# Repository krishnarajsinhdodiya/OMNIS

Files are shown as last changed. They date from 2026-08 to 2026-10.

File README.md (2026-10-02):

# OMNIS

**O**mnidirectional **M**obility and **N**on-holonomic **I**nertial **S**tabilization

A four-wheel robot platform where every wheel is driven by its own stepper motor,
built from scratch on the ESP32-S3 as a personal embedded-systems portfolio
project.

Two headline capabilities:

1. **Holonomic drive** — mecanum angled-roller wheels give full directional
   control: strafe, rotate in place, and move diagonally without turning first.
2. **Self-balancing mode** — the platform can tip up and balance/drive on two
   wheels, Segway-style, in addition to normal four-wheel driving.

All four steppers stay powered during two-wheel balance mode. That is
deliberate: the platform must be able to balance on *either* side, so if it is
flipped mid-run the new pair of wheels is immediately drivable. The balance
controller detects which side is down and re-maps which two wheels provide
balance thrust.

---

## Where the working firmware is

> ### 👉 [`omnis-superloop-mvp/`](omnis-superloop-mvp/) — the complete, buildable firmware
>
> A **plain superloop with no FreeRTOS tasks, queues, semaphores or mutexes**.
> All seven stages are built, host-tested and committed: 500 Hz dual-IMU EKF,
> mecanum kinematics, CRSF radio, RMT step generation, fault handling, arming
> supervisor and the two-wheel balance controller.
>
> **Start at [`omnis-superloop-mvp/TESTING.md`](omnis-superloop-mvp/TESTING.md)
> §0 before applying power** — board Rev 2.0 hardwires the A4988 enable, so the
> motors are live whenever 12 V is present.

The repository holds **two** firmware trees, and it is worth being clear about
which is which:

| Tree | What it is | State |
|---|---|---|
| [`omnis-superloop-mvp/`](omnis-superloop-mvp/) | The **deadline build**. Bare superloop, no RTOS primitives, everything needed to drive and balance | **Complete**, host-tested, awaiting bench bring-up on the assembled Rev 2.0 board |
| `main/` (repository root) | The **future FreeRTOS build** described in [`assets/documentation/omnis-info.md`](assets/documentation/omnis-info.md) | Still at the ESP-IDF hello-world stage — a placeholder, not abandoned work |

The superloop MVP exists because the full RTOS architecture is a learning
project with a longer runway than the delivery deadline allowed. Features left
out of it — OLED and buttons, microSD/FATFS and `params.json`, data logging,
OTA/Wi-Fi, battery sensing — are **deferred, not abandoned**, and the design for
each is already written down in the info file.

---

## Repository layout

```
OMNIS/
├── omnis-superloop-mvp/            ★ the working firmware — start here
│   ├── main/                         44 sources; see OPERATIONS_GUIDE.md §3
│   │   ├── main.c                    boot sequence + the superloop itself
│   │   ├── tick.{c,h}                500 Hz GPTimer, one flag, no RTOS
│   │   ├── imu.{c,h} mpu6050.*       dual MPU6050 over I²C
│   │   ├── attitude_ekf.* imu_fusion.*   per-IMU EKF + inverse-covariance fusion
│   │   ├── mecanum_kinematics.*      IK/FK for the parallel-roller layout
│   │   ├── drive.{c,h}               sticks → body velocity → wheel rates
│   │   ├── crsf*.{c,h} rc_input.*    ExpressLRS radio
│   │   ├── step_wave.* step_gen.*    STEP pulses via the RMT peripheral
│   │   ├── balance.{c,h} pid.*       two-wheel balance controller
│   │   ├── fault.* buzzer*.* supervisor.*   safety and arming
│   │   └── omnis_{pins,params,config}.*     board map, tunables, switches
│   ├── test/                         7 host suites, no hardware needed
│   ├── OPERATIONS_GUIDE.md           build, architecture, file index, tuning
│   ├── TESTING.md                    bench bring-up, stage by stage
│   ├── README.md                     overview and stage status
│   └── BUILD-LOG.md                  scope, decisions, construction history
│
├── assets/
│   ├── kinematics/                   drivetrain maths, derived from scratch
│   │   ├── mecanum-kinematics-derivation.md     the full derivation
│   │   ├── mecanum-kinematics-reference.md      equations and verified numbers
│   │   ├── mecanum-kinematics-code-explained.md line-by-line walkthrough
│   │   └── mecanum_kinematics.{c,h}             the module itself
│   ├── control/                      EKF, fusion and PID: derivations + modules
│   ├── documentation/
│   │   ├── omnis-info.md             full design spec + what the MVP does — ONE copy
│   │   ├── s3-pro-docs/              board pinout, datasheet, CAD model
│   │   └── setup-guides/             toolchain, VS Code, ESP32 command reference
│   └── pcb/                          KiCad project and schematics
│
├── main/                             future FreeRTOS build (hello-world stub)
├── CMakeLists.txt                    root ESP-IDF project
├── .devcontainer/                    QEMU/Linux container (no board access)
└── .vscode/
```

The modules under `assets/kinematics/` and `assets/control/` are **byte-identical**
to the copies in `omnis-superloop-mvp/main/`. They live in `assets/` with their
derivations so the maths and the code that implements it stay next to each other.

---

## Drivetrain — read this before touching the kinematics

The wheels are **not** in the textbook X-drive arrangement. Mounting-shaft and
motor constraints put the **same roller tilt on both left wheels** and the
mirrored tilt on **both right wheels**:

```
        FL  /                 \  FR          left  pair  FL, RL  ->  δ = -1
        RL  /                 \  RR          right pair  FR, RR  ->  δ = +1
```

The standard mecanum mixing matrix does not describe this robot. The inverse and
forward kinematics were **re-derived from first principles** for this layout —
see [`assets/kinematics/mecanum-kinematics-derivation.md`](assets/kinematics/mecanum-kinematics-derivation.md).

Four consequences worth knowing up front:

- **Strafe splits along the sides**, not the diagonals. The `vx = vy` bench test
  idles the whole **left side**, not the FL/RR diagonal.
- **The two axles have different yaw levers** — `(L+W)/2` at the front and
  `(L−W)/2` at the rear, a **64.7:1** ratio on this frame. During a pure spin
  the rear wheels barely turn. That is correct, not a fault.
- **Still fully holonomic and no slower.** `det(MᵀM) = 4L²`, non-zero for any
  real chassis, and the peak wheel rate per unit of commanded motion is
  unchanged — same top speed, strafe speed and yaw rate as an X-drive.
- **Odometry is noisier.** The strafe and yaw columns meet at 44° instead of
  90°, amplifying per-wheel error by 1.44× on `vy` and 2.03× on `w`.

The layout is stated in exactly one place — the four `MECANUM_DELTA_*` constants
in `mecanum_kinematics.h` — and everything else is computed from them. If the
robot strafes the wrong way, negate all four together; never fix it with a `DIR`
invert flag. [`OPERATIONS_GUIDE.md §4.2`](omnis-superloop-mvp/OPERATIONS_GUIDE.md)
has the two-direction bench test that tells the two failures apart.

---

## Hardware

| Module | Part | Notes |
|---|---|---|
| MCU | **ESP32-S3-WROOM-1-N16R8** on an EdgeHax S3 Pro dev board | 16 MB flash / 8 MB Octal PSRAM |
| Wheel motors (×4) | Nidec **KV4239-T3B004** | 2-phase hybrid stepper, NEMA17-class (42 mm) |
| Stepper drivers (×4) | **A4988** | Fixed 1/16 microstepping → 3200 microsteps/rev |
| Wheels (×4) | Mecanum omnidirectional, 60 mm | **Lateral parallel roller layout** — see above |
| IMUs (×2) | **MPU6050** at `0x68` and `0x69` | Diagonally opposite corners, mounted **antiparallel**; fused by inverse covariance |
| Display | **SSD1306** 128×64 I²C OLED | Deferred in the MVP |
| RC link | **RadioMaster Pocket** TX + **ExpressLRS Nano** Rx | CRSF over UART, 420000 baud |
| Storage | Onboard microSD (SPI mode, FAT32) | Deferred in the MVP |
| Buzzer | 3-pin buzzer module | Fault and failsafe cues |
| Buttons | 6× tactile | **Active-HIGH**, needs pull-downs. Deferred in the MVP |
| Power | 3S LiPo → **L7805CV** 5 V logic rail | Battery divider present; sensing deferred in the MVP |

Schematic: [`assets/pcb/`](assets/pcb/) (KiCad project, Rev 2.0).

### GPIO map — board Rev 2.0

Traced wire-by-wire from the KiCad schematic, not read off a drawing. The
authoritative copy is
[`omnis-superloop-mvp/main/omnis_pins.h`](omnis-superloop-mvp/main/omnis_pins.h).

| GPIO | Function |
|---|---|
| 4, 5 | Front-Left STEP / DIR |
| 40, 38 | Front-Right STEP / DIR |
| 15, 46 | Rear-Left STEP / DIR (46 is a strapping pin) |
| 21, 42 | Rear-Right STEP / DIR |
| 8, 9 | I²C SDA / SCL — OLED and both MPU6050s |
| 7 | IMU interrupt |
| 17, 18 | UART to the ExpressLRS receiver — ESP **TX** / **RX** |
| 16 | Buzzer |

**Three gotchas worth knowing before you wire or flash anything:**

- **`COM_ENA` is gone on Rev 2.0.** The A4988 enable is hardwired, so the motors
  are energised whenever 12 V is present — before the firmware runs, and while
  it is halted in a fault. Nothing in software can de-energise them. The
  failsafe is therefore "stop STEP pulses, motors hold", and setting the four
  `Vref` current limits is a **prerequisite to first power-up**, not a
  calibration step.
- The schematic's `RX` / `TX` net names are from the *receiver's* perspective.
  GPIO17 is the ESP32's **TX** and GPIO18 is its **RX** — the reverse of the
  labels. The firmware auto-detects the RX pin anyway.
- GPIO46 is a strapping pin and GPIO38–42 sit on the default JTAG pins.
  Everything behaves normally as long as nothing holds them through a power
  cycle.

---

## Firmware architecture (superloop MVP)

```
            GPTimer ISR (500 Hz) ── sets a volatile flag, nothing else
                     │
   app_main ─ while(1) ─ tick_wait() ─────────────────────────────────────────┐
     │                                                                        │
     │  1. SENSE   imu_update()      2× MPU6050 on I²C → mount → bias → EKF → fuse
     │             crsf_poll()       UART1 RX-only → CRSF parser → channels
     │                                                                        │
     │  2. JUDGE   faults            IMU comm/disagree · link loss · tilt · overrun
     │             supervisor        DISARMED / ARMED-FLAT / BAL-SETTLE / BALANCE
     │                                                                        │
     │  3. ACT     flat:     sticks → IK → clamp → deadband → slew ─┐         │
     │             balance:  lean PID (balance frame) → wheel pair ─┼→ step_gen_update()
     │             else:     step_gen_stop()                         │    RMT ISR chains
     │                                                               │    ~2 ms bursts
     │  4. REPORT  buzzer (every tick) · telemetry (once a second)            │
     └────────────────────────────────────────────────────────────────────────┘
```

**The no-RTOS rule.** No FreeRTOS primitive appears in OMNIS-authored code —
ESP-IDF driver internals are treated as hardware. It was checked mechanically,
not merely followed: neither the `main/` sources nor the undefined symbols of the
compiled `libmain.a` contain any FreeRTOS task, queue, semaphore, event-group,
timer or port symbol.

The superloop is pinned to **CPU1** with that core's idle-task watchdog disabled
— a superloop never yields, so the idle task never runs.

Full explanation, file index and tuning cheat sheet:
[`omnis-superloop-mvp/OPERATIONS_GUIDE.md`](omnis-superloop-mvp/OPERATIONS_GUIDE.md).

### Control and estimation

Each MPU6050 runs its own 4-state EKF — `[roll, pitch, gyro_bias_roll,
gyro_bias_pitch]` — with adaptive measurement noise that distrusts the
accelerometer whenever `|‖a‖ − 1g|` exceeds ~0.2 g, i.e. exactly when the
platform is accelerating rather than merely tilted. Because roll couples only to
`bias_roll` and pitch only to `bias_pitch`, the 4×4 filter decomposes **exactly**
into two independent 2-state filters — no matrix inverse anywhere.

A fusion layer takes the inverse-covariance-weighted average of the two
estimates and raises a fault if they disagree by more than 15°, failing safe
instead of averaging through a bad sensor. Disagreement is measured on the
**gravity vectors**, not on Euler angles, so it stays meaningful at any attitude.

Balance runs in a dedicated **balance frame** rather than the flat body frame,
because flat-frame pitch folds at exactly the balance point — 85° and 95° both
read 85°, losing the lean direction where a balancer most needs it. The
controller is an inner 500 Hz PID on lean angle (rate taken straight from the
gyro for latency) plus a slow 20 Hz outer loop that biases the lean setpoint to
bleed off sustained forward effort. There are no wheel encoders, so this is the
honest ceiling of the current BOM — an encoder pair is the single
highest-leverage hardware upgrade available.

### Safety

- **Arming supervisor** with LOW→HIGH edge consumption: a fault that clears
  while the switch is still up does not re-arm the robot on its own.
- **CRSF link-loss, IMU comm failure, IMU disagreement, tilt and loop overrun**
  all latch faults and stop STEP pulses within the same tick.
- **Failsafe policy:** "hold last value" is explicitly the wrong default here — a
  dropped link mid-deflection would leave the robot executing that command
  unattended.
- Balance mode refuses to arm with zero gains, because a zero-gain balancer
  simply falls over.

---

## Building

Requires **ESP-IDF v6.0.2** natively for hardware work. Activate it with the
tools script — `export.sh` looks for a Python 3.11 virtualenv while this install
runs on 3.14:

```bash
. ~/.espressif/tools/activate_idf_v6.0.2.sh
```

Build and flash the working firmware:

```bash
cd /Volumes/Projects/OMNIS && idf.py -C omnis-superloop-mvp build
```

```bash
cd /Volumes/Projects/OMNIS && idf.py -C omnis-superloop-mvp -p /dev/cu.usbmodem101 flash monitor
```

Run the host test suites — no hardware, no ESP-IDF:

```bash
cd /Volumes/Projects/OMNIS/omnis-superloop-mvp && ./test/run_host_tests.sh
```

Full setup, including the native-vs-devcontainer split, is in
[`assets/documentation/setup-guides/phase0-toolchain-environment.md`](assets/documentation/setup-guides/phase0-toolchain-environment.md).
The devcontainer has **no USB passthrough** — it is for QEMU experiments only.
All real board work happens natively.

---

## Status

| Stage (superloop MVP) | Built + host-tested | Verified on hardware |
|---|---|---|
| 1 Timing spine | ✅ | ✅ 2026-09-07 (Rev 1 board): 500 Hz, zero overruns |
| 2 Kinematics | ✅ | ✅ boot self-check passed on the FPU |
| 3 IMUs + EKF | ✅ | ✅ |
| 4 Radio | ✅ | ✅ |
| 5 Step generation | ✅ | ✅ |
| 6 Faults + supervisor | ✅ | ✅ |

Not known until the assembled Rev 2.0 board runs: real I²C time per tick, IMU
mounting descriptors, motor `DIR` polarities, radio channel order, and every
balance gain. All five are **parameters**, not code changes —
[`OPERATIONS_GUIDE.md §4`](omnis-superloop-mvp/OPERATIONS_GUIDE.md) is the cheat
sheet.

### Roadmap beyond the MVP

Everything deferred from the superloop build, in the order it is worth adding:

1. **FATFS mount + `params.json` loader** with its fallback chain — so tuning
   stops requiring a rebuild
2. **Data logging** to append-only JSON Lines under `/sdcard/logs/`
3. **On-board wheel encoders** — the single highest-leverage hardware upgrade,
   and what the velocity-bias outer loop is really waiting for
4. **OLED and the button/menu state machine**
5. **OTA over Wi-Fi** with a factory slot and rollback verified against a
   deliberately broken image
6. **The full FreeRTOS architecture** at the repository root, once it has been
   learned properly rather than adopted in a hurry

### Open questions

- Internal vs. external button pull-downs
- Heading-hold: hold-to-engage or press-to-toggle
- What the transmitter's trim potentiometer trims — static balance-setpoint bias
  or live control gain
- A4988 `Vref` current limits, unset until the motors are on the bench

---

## License

Not yet specified.

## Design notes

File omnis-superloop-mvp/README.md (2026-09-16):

# OMNIS Superloop MVP

Firmware for the OMNIS robot — four-wheel mecanum drive that can also stand up
and balance on either wheel pair — written as a **plain superloop with no FreeRTOS
tasks, queues, semaphores or mutexes**. It is the deadline build that gets the
robot driving and balancing before the full FreeRTOS architecture in
[`../assets/documentation/omnis-info.md`](../assets/documentation/omnis-info.md) is
learned and implemented. Deferred features are deferred, not abandoned.

**Target:** ESP32-S3 (EdgeHax S3 Pro / DevKitC-1 class), board Rev 2.0 · ESP-IDF v6.0.2

| Document | Read it for |
|---|---|
| **[TESTING.md](TESTING.md)** | Bench bring-up, stage by stage. **Start here before powering anything.** |
| **[OPERATIONS_GUIDE.md](OPERATIONS_GUIDE.md)** | Build and flash, the superloop explained, a file-by-file index, and the tuning cheat sheet |
| [BUILD-LOG.md](BUILD-LOG.md) | The full history: what was built, what was learned, every decision, every bug found. **Also holds the scope, the settled decisions 1a/1b/1c and the stage-by-stage commit table** — `PLAN.md` was folded into it once the build finished |
| [../assets/documentation/omnis-info.md](../assets/documentation/omnis-info.md) | **The project info file — one copy, for the whole project.** The full specification, with `> **Superloop MVP:**` notes under each section saying what this build actually does |

---

## What it does

| In scope | Where |
|---|---|
| 500 Hz loop: dual-MPU6050 attitude EKF, inverse-covariance fusion, 15° disagreement fault | `imu.c`, `attitude_ekf.c`, `imu_fusion.c` |
| 4-wheel mecanum IK/FK, re-derived for the **lateral parallel roller** layout | `mecanum_kinematics.c`, `drive.c` |
| CRSF / ExpressLRS radio: throttle→vx, yaw→w, pitch+roll→vx/vy, arm, mode, speed | `crsf*.c`, `rc_input.c` |
| STEP pulses for four A4988s on the RMT peripheral, nothing in the hot path | `step_wave.c`, `step_gen.c` |
| Buzzer fault / failsafe signalling, arming supervisor | `fault.c`, `buzzer*.c`, `supervisor.c` |
| Two-wheel balance: lean PID in a dedicated balance frame | `balance.c`, `pid.c` |

**Excluded — deferred, not abandoned:** OLED and buttons, microSD / FATFS and
`params.json`, data logging, OTA and Wi-Fi, battery voltage sensing.

---

## Architecture

```
            GPTimer ISR (500 Hz) ── sets a volatile flag, nothing else
                     │
   app_main ─ while(1) ─ tick_wait() ─────────────────────────────────────────┐
     │                                                                        │
     │  1. SENSE   imu_update()      2x MPU6050 on I2C → mount → bias → EKF → fuse
     │             crsf_poll()       UART1 RX-only → CRSF parser → channels
     │                                                                        │
     │  2. JUDGE   faults            IMU comm/disagree · link loss · tilt · overrun
     │             supervisor        DISARMED / ARMED-FLAT / BAL-SETTLE / BALANCE
     │                                                                        │
     │  3. ACT     flat:     sticks → IK → clamp → deadband → slew ─┐         │
     │             balance:  lean PID (balance frame) → wheel pair ─┼→ step_gen_update()
     │             else:     step_gen_stop()                         │    RMT ISR chains
     │                                                               │    ~2 ms bursts
     │  4. REPORT  buzzer (every tick) · telemetry (once a second)            │
     └────────────────────────────────────────────────────────────────────────┘
```

**The no-RTOS rule** (BUILD-LOG.md, Planning 1a): no RTOS primitive in OMNIS-authored code.
ESP-IDF driver internals are treated as hardware. The rule was checked mechanically,
not just followed: neither `main/` source nor the undefined symbols of the compiled
`libmain.a` contain any FreeRTOS task, queue, semaphore, event-group, timer or port
symbol.

**On board Rev 2.0 the A4988 enable is hardwired**, so the motors are energised
whenever 12 V is present and the supervisor is the entire safety story: STEP pulses
exist only while armed. Read TESTING.md §0.

---

## The wheel layout is not an X-drive

Both left wheels carry the same roller tilt and both right wheels the mirror:

```
        FL  /                 \  FR          left  pair  FL, RL  ->  δ = -1
        RL  /                 \  RR          right pair  FR, RR  ->  δ = +1
```

So the standard mecanum matrix does not apply. The kinematics were re-derived
from first principles ([derivation](../assets/kinematics/mecanum-kinematics-derivation.md)).
What changes in practice:

- **Strafe splits along the sides**, not the diagonals. `vx = vy` idles the whole
  **left side**; `vx = -vy` idles the right.
- **The front axle carries 98.5% of the yaw authority** (lever ratio 64.7:1), so
  during a spin the rear wheels crawl and, below ≈0.34 rad/s, the deadband holds
  them still. Correct, not a dead motor.
- Still fully holonomic, and **no slower** — same top speed, strafe speed and yaw
  rate. The cost is odometry precision: 1.44× on `vy`, 2.03× on `w`.

The layout lives in four constants (`MECANUM_DELTA_*` in `mecanum_kinematics.h`).
If forward motion is right but strafe is backwards, negate all four together —
never reach for a `dir_invert` flag. [OPERATIONS_GUIDE.md §4.2](OPERATIONS_GUIDE.md)
has the test that tells those two failures apart.

---

## Layout

```
omnis-superloop-mvp/
  main/
    main.c                   boot sequence + the superloop
    omnis_pins.h             board Rev 2.0 GPIO map (traced from the KiCad file)
    omnis_params.{c,h}       every tunable number (future params.json)
    omnis_config.h           build-time switches
    tick.{c,h}               500 Hz GPTimer
    mpu6050{.c,.h,_regs.h}   IMU driver
    imu.{c,h}                both IMUs: calibration, fusion, frames, mount wizard
    attitude_ekf.{c,h}  ┐
    imu_fusion.{c,h}    │    byte-identical to assets/control/
    pid.{c,h}           │
    omnis_imu_mounting.h┘
    mecanum_kinematics.{c,h} byte-identical to assets/kinematics/; parallel-roller IK/FK
    drive.{c,h}              sticks → wheel rates, slew limiter
    crsf_parser.{c,h}        pure CRSF parser
    crsf.{c,h}               UART glue, RX-pin auto-detect
    rc_input.{c,h}           channels → sticks, switches, arm request
    step_wave.{c,h}          pure STEP waveform generator
    step_gen.{c,h}           RMT glue for four wheels
    fault.{c,h}              fault latch
    buzzer_pattern.{c,h}     pure buzzer patterns
    buzzer.{c,h}             buzzer GPIO
    supervisor.{c,h}         arming state machine
    balance.{c,h}            balance controller
  test/
    run_host_tests.sh        runs every suite
    test_*.c                 host tests, no hardware
    crsf_golden.h            reference frames from an independent implementation
```

Every pure module (no ESP-IDF includes) is host-tested. The hardware glue
(`imu.c`, `crsf.c`, `step_gen.c`, `buzzer.c`, `main.c`) is exercised by the bench
procedure in TESTING.md.

---

## Build, flash, test

```bash
. ~/.espressif/tools/activate_idf_v6.0.2.sh
```

```bash
cd /Volumes/Projects/OMNIS && idf.py -C omnis-superloop-mvp build
```

```bash
cd /Volumes/Projects/OMNIS && idf.py -C omnis-superloop-mvp -p /dev/cu.usbmodem101 flash monitor
```

```bash
cd /Volumes/Projects/OMNIS/omnis-superloop-mvp && ./test/run_host_tests.sh
```

Full instructions, including the ESP-IDF activation quirk and what to do when
flashing will not connect, are in [OPERATIONS_GUIDE.md §1](OPERATIONS_GUIDE.md).

---

## Status

| Stage | Built + host-tested | Verified on hardware |
|---|---|---|
| 1 Timing spine | ✅ | ✅ 2026-09-07 (Rev 1 board): 500 Hz, zero overruns, no jitter |
| 2 Kinematics | ✅ | boot self-check passed on the FPU (2026-09-07) |
| 3 IMUs + EKF | ✅ | ⬜ |
| 4 Radio | ✅ | ⬜ |
| 5 Step generation | ✅ | ⬜ |
| 6 Faults + supervisor | ✅ | ⬜ |
| 7 Balance | ✅ | ⬜ |

Not yet known until the board runs: real I²C time per tick, IMU mounting on Rev 2.0,
motor DIR polarities, radio channel order, and every balance gain.

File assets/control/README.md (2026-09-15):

# OMNIS — Control & Estimation

Sensor fusion, attitude EKF, and balance PID for the OMNIS platform. Companion
to [`../kinematics/`](../kinematics/), which covers the mecanum drivetrain.

Implements `omnis-info.md` §11 (EKF and dual-IMU fusion), §12 (calibration
hooks) and §13 (balance control).

## Layout

| File | What it is |
|---|---|
| [`attitude-ekf-reference.md`](attitude-ekf-reference.md) | State model, matrices, tuning, verified numbers |
| [`attitude-ekf-derivation.md`](attitude-ekf-derivation.md) | Why the filter has this form; the singularity; what was left out |
| [`sensor-fusion-reference.md`](sensor-fusion-reference.md) | Mounting, fusion, the 15° fault, side detection |
| [`pid-reference.md`](pid-reference.md) | Cascaded architecture, anti-windup, tuning procedure |
| [`control-code-explained.md`](control-code-explained.md) | Integration example and line-by-line walkthrough |
| `attitude_ekf.h/.c` | Per-IMU 4-state attitude filter |
| `imu_fusion.h/.c` | Mounting remap, fusion, fault, side detection |
| `pid.h/.c` | Inner PID + outer velocity-bias loop |
| `omnis_imu_mounting.h` | **As-built** chassis frame, corner labelling and IMU mount constants |
| `test_control.c` | 97 host-side assertions |
| `run_host_tests.sh` | Build and run them — no ESP-IDF, no hardware |

## As-built chassis facts

Front edge is the OLED / button end. Body frame is right-handed, **+X forward,
+Y left, +Z up** — identical to the kinematics convention.

| | Corner | I2C | Faces | Mount |
|---|---|---|---|---|
| IMU A | front-left | `0x68` | forward | `IMU_MOUNT_IDENTITY` |
| IMU B | rear-right | `0x69` | rearward | `IMU_MOUNT_ROT_Z_180` |

Balance mode tips about the body **Y** axis, so the lean angle is **pitch** and
roll is gimbal-locked and unused. The grounded pair is FL+FR or RL+RR.

**Positive pitch = nose DOWN**, opposite to the aerospace convention. It falls
out of `pitch = atan2(−ax, hypot(ay,az))` and is asserted in the tests.

See [`omnis_imu_mounting.h`](omnis_imu_mounting.h) for the chassis diagram.

## Verify

```bash
./run_host_tests.sh
```

## Four things that will bite

1. **Correct the IMU mounting before the EKF, not after.** OMNIS's two modules
   *are* mounted antiparallel (confirmed 2026-09-05) — uncorrected, that makes
   two healthy sensors read 20° apart and the fault fires at boot, every boot.
   Constants in `omnis_imu_mounting.h`; derive them for real with
   `imu_mount_resolve()` rather than trusting a silkscreen arrow.
   → `sensor-fusion-reference.md` §2, §2.5
2. **Never compare Euler angles to detect IMU disagreement.** Balance mode sits
   at pitch ≈ 90° where roll is gimbal-locked; a 60° roll difference there is
   only 3.46° of real disagreement. Compare gravity vectors. → §3
3. **The outer velocity-bias loop's sign.** Forward drive effort must command a
   *backward* lean. Wrong sign accelerates until it falls over.
   → `pid-reference.md` §4
4. **Never use the flat-frame pitch as the balance lean angle.** At the balance
   point (±90°) `atan2(-ax, hypot(ay,az))` folds: nose-down 85° and 95° both read
   85°, so which way the robot is falling is lost. Balance mode rotates into a
   frame where the pose is level (`OMNIS_IMU_BALANCE_FRAME_*`).
   → `attitude-ekf-derivation.md` §7

## Units

Radians and rad/s throughout. Accelerometer in **g**, not m/s² — the adaptive-R
gate keys off `|a|` deviating from 1.0, so m/s² silently rejects every update.
Convert once at the driver boundary.

Body frame matches the kinematics convention exactly: **+X forward, +Y left,
+Z up**.

## Deliberately not here

- Gyro/accel calibration routines (§12) — these modules *consume* calibration
  via `attitude_ekf_set_gyro_bias()`; producing it is a driver concern.
- Any I2C or peripheral access. Pure arithmetic, host-testable.
- Numeric PID gains. §13d declines to guess them without mass, CG height and
  wheel radius; `pid_config_defaults()` sets them to zero on purpose.
- Lever-arm compensation. §11b defers it to v2; needs measured IMU positions.

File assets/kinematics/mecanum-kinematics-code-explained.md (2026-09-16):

# Mecanum Kinematics — Code Walkthrough

**Project:** OMNIS · 4-wheel holonomic mecanum platform
**Layout:** **lateral parallel rollers** — left pair alike, right pair mirrored
**Companion files:** [`mecanum_kinematics.c`](mecanum_kinematics.c) ·
[`mecanum_kinematics.h`](mecanum_kinematics.h)

This document reproduces the firmware block by block and explains what each
piece does and why it is written that way. The maths behind it is in
[`mecanum-kinematics-derivation.md`](mecanum-kinematics-derivation.md); the
equations alone are in
[`mecanum-kinematics-reference.md`](mecanum-kinematics-reference.md).

The code compiles clean under `cc -std=c99 -Wall -Wextra -Werror` and has been
runtime-verified against the numbers in §7 of the reference document. The
transcript in §9 is real output from the shipped source, not a hand-worked
example.

---

## 1. Constants and types

```c
#define MOTOR_FULL_STEPS_PER_REV   200.0f   /* 1.8 deg/step NEMA17-class    */
#define A4988_MICROSTEPS            16.0f   /* MS1/MS2/MS3 = HIGH           */
#define MICROSTEPS_PER_REV   (MOTOR_FULL_STEPS_PER_REV * A4988_MICROSTEPS)

#define STEPS_PER_RAD        (MICROSTEPS_PER_REV / (2.0f * (float)M_PI))
```

**Why these are macros and the geometry is not.** These four values describe
things that are physically soldered or jumpered: the motor's step angle and the
A4988's microstep jumpers tied HIGH. They cannot change without a hardware
change, so compile-time is the right place for them. Wheel radius and frame
dimensions *can* change, so they arrive as function arguments instead.

`MICROSTEPS_PER_REV` evaluates to 3200. `STEPS_PER_RAD` evaluates to
**509.295818**, the single constant converting rad/s to microsteps/s. Writing it
as an expression rather than a literal means changing the microstep jumpers is a
one-line edit and the derived constant follows automatically.

The `(float)M_PI` cast matters: `M_PI` is a `double`. Without the cast the whole
expression promotes to double, and on an ESP32-S3 that means software
double-precision arithmetic instead of the hardware single-precision FPU.

### The roller handedness constants — the only statement of the layout

```c
#define MECANUM_DELTA_FL   (-1)
#define MECANUM_DELTA_FR   (+1)
#define MECANUM_DELTA_RL   (-1)
#define MECANUM_DELTA_RR   (+1)

#define MECANUM_DELTA_LEFT  MECANUM_DELTA_FL
```

`δ_i` is the sign distinguishing the two mirrored roller tilts: the roller axis
of wheel *i* projected into the ground plane is `(1, δ_i)/√2` in body
coordinates. Seen from above with the robot facing up the page, `δ = -1` draws
as `/` and `δ = +1` as `\`.

Read down the list: **both left wheels −1, both right wheels +1**. That is the
lateral parallel layout, and it is stated here and nowhere else. Every `vy` sign
and both yaw lever arms in this file are *computed from* these four numbers
rather than written out independently, so the two can never disagree.

**Why integers and not floats.** The assertions below need integer constant
expressions; C only permits floating constants inside `_Static_assert` as the
immediate operand of a cast. Making them `int` and casting at the point of use
keeps the assertions readable.

```c
_Static_assert(MECANUM_DELTA_FL == MECANUM_DELTA_RL, "left pair must share a roller tilt");
_Static_assert(MECANUM_DELTA_FR == MECANUM_DELTA_RR, "right pair must share a roller tilt");
_Static_assert(MECANUM_DELTA_FR == -MECANUM_DELTA_FL, "the two sides must be mirrored");
_Static_assert(MECANUM_DELTA_FL == 1 || MECANUM_DELTA_FL == -1, "handedness is +1 or -1");
```

These are not decoration. `mecanum_inverse()` below is fully general — it would
happily compute an X-drive if you gave it X-drive deltas — but `mecanum_forward()`
uses a **closed-form pseudoinverse derived specifically for the parallel
family**. Setting the deltas back to an X-drive would leave the IK correct and
the FK quietly wrong, which is the worst possible failure: forward motion looks
fine and dead reckoning drifts. The assertions turn that into a compile error
naming the derivation section to read.

```c
typedef struct { float fl, fr, rl, rr; } wheel_rates_t;   /* [microsteps/s] */
typedef struct { float vx, vy, w;      } body_vel_t;
typedef struct { float fl, fr, rl, rr; } mecanum_levers_t; /* [mm] */
```

Named structs rather than four loose floats or a `float[4]`. The array form
invites indexing bugs — `wheels[2]` is meaningless at a glance, `rates.rl` is
not. Returning them by value is cheap and avoids output-parameter aliasing.

**The rates are signed.** Sign carries the `DIR` pin state; magnitude carries
the `STEP` pulse rate. Keeping them in one signed float means the kinematics
never has to know about GPIO.

`mecanum_levers_t` is new in this edition. Under the X-drive there was a single
lever arm `k` and a struct would have been silly; under parallel rollers the
four wheels genuinely have different levers and they are worth naming.

---

## 2. The yaw lever arms

```c
mecanum_levers_t mecanum_yaw_levers(float wheelbase_mm, float track_width_mm)
{
    const float half_l = 0.5f * wheelbase_mm;
    const float half_w = 0.5f * track_width_mm;

    mecanum_levers_t k;
    k.fl = (float)MECANUM_DELTA_FL * ( half_l) - ( half_w);
    k.fr = (float)MECANUM_DELTA_FR * ( half_l) - (-half_w);
    k.rl = (float)MECANUM_DELTA_RL * (-half_l) - ( half_w);
    k.rr = (float)MECANUM_DELTA_RR * (-half_l) - (-half_w);
    return k;
}
```

This is derivation (5.3)'s `κ_i = δ_i·x_i − y_i` transcribed literally, with the
wheel positions `x_i = ±L/2` (front positive) and `y_i = ±W/2` (left positive)
written out in place rather than tabulated. The doubled parentheses and the
visible `-(-half_w)` are deliberate: they keep each line in one-to-one
correspondence with a row of the derivation table, so the two can be checked
against each other by eye.

For the as-built geometry this evaluates to:

```
FL = -226.5    FR = +226.5    RL = -3.5    RR = +3.5   [mm]
```

**The front pair gets `±(L+W)/2` and the rear pair `±(L−W)/2`.** Under an
X-drive all four came out at `±(L+W)/2` and a single `k` sufficed. Here the
front axle's lever is **64.7×** the rear's, so the front pair supplies 98.5% of
the yaw authority and the rear wheels barely turn during a spin.

Two things to know about the rear lever:

- It is **small**, so a slow yaw command will push the rear pair below the
  deadband while the front pair still drives. Correct, not a dead motor.
- Its **sign depends on whether the frame is longer or wider**. `(L−W)/2` is
  −3.5 mm on OMNIS (wider than long) and would be positive on a longer chassis,
  zero on a square one. Nothing breaks at the crossover — §8.2 of the derivation
  shows the matrix stays full rank — but do not memorise which way the rear
  wheels turn during a spin. It is not a robust fact.

The deltas are compile-time constants, so at `-O2` each of these four lines
folds to a single add of two halved parameters. There is no runtime cost to the
generality.

---

## 3. Inverse kinematics

```c
wheel_rates_t mecanum_inverse(float vx, float vy, float w,
                              float wheel_radius_mm,
                              float wheelbase_mm,
                              float track_width_mm)
{
```

The three geometry values are **parameters, not globals**. This is the whole
point of the exercise: the caller passes `g_params.wheel_radius_mm` and friends
straight from `params.json`, and resizing the frame never touches this function.

```c
    const mecanum_levers_t k = mecanum_yaw_levers(wheelbase_mm, track_width_mm);
    const float inv_r = 1.0f / wheel_radius_mm;
```

One divide instead of four. Division is markedly slower than multiplication even
with the S3's FPU, and this function runs in the 500 Hz control loop.

```c
    const float w_fl = (vx + (float)MECANUM_DELTA_FL * vy + k.fl * w) * inv_r;
    const float w_fr = (vx + (float)MECANUM_DELTA_FR * vy + k.fr * w) * inv_r;
    const float w_rl = (vx + (float)MECANUM_DELTA_RL * vy + k.rl * w) * inv_r;
    const float w_rr = (vx + (float)MECANUM_DELTA_RR * vy + k.rr * w) * inv_r;
```

**One line per wheel, and every line is the same formula.** This is derivation
(5.3) written once:

```
r·ω_i = vx + δ_i·vy + w·κ_i
```

The previous edition wrote the signs out by hand (`vx - vy - yaw_term` and so
on). Writing them as `δ_i` and `κ_i` instead is not stylistic: it makes the four
rows *structurally* identical, so there is no row in which a sign can be wrong
independently of the others. A mirrored build is now four `#define`s, and a
half-applied mirror is not expressible.

Substituting the constants, this expands to the matrix in the reference:

| | `vx` | `vy` | `w` |
|---|---|---|---|
| FL | + | **−** | **−k** |
| FR | + | **+** | **+k** |
| RL | + | **−** | **+m** |
| RR | + | **+** | **−m** |

with `k = (L+W)/2` and `m = (L−W)/2`.

- The `vy` column splits along **sides**: left pair negative, right pair
  positive, all four equal magnitude. Under an X-drive this split along the
  diagonals.
- The `w` column **also** splits along sides — but with the front pair 64.7×
  larger than the rear.

So strafe and yaw now share a sign pattern and are distinguished only by the
front:rear magnitude ratio, 1:1 against 64.7:1. They remain independent
directions — the platform is still fully holonomic, and derivation §8.2 proves
rank 3 for any non-zero wheelbase — but they are no longer *orthogonal* wheel
patterns, and §4 is where that bill arrives.

**Do not edit these signs to fix a motor spinning backwards.** The `vy` and `w`
signs both derive from the same `δ_i`, so they are not independent — flipping
one alone produces a matrix that is not the kinematics of any physical robot.
Motor mirroring belongs in §8.

```c
    wheel_rates_t out;
    out.fl = w_fl * STEPS_PER_RAD;
    /* ... */
    return out;
}
```

The rad/s → microsteps/s conversion, applied last. Doing it as a separate final
step (rather than folding `STEPS_PER_RAD` into `inv_r`) keeps the intermediate
`w_*` values in real physical units, which makes them meaningful in a debugger
and lets you sanity-check against the derivation directly.

---

## 4. Forward kinematics

```c
body_vel_t mecanum_forward(const wheel_rates_t *f, float wheel_radius_mm,
                           float wheelbase_mm, float track_width_mm)
{
    body_vel_t v = { 0.0f, 0.0f, 0.0f };

    if (f == NULL || !(wheelbase_mm > 0.0f)) {
        return v;
    }
```

**Why the wheelbase is guarded and the previous edition's divisor was not.**
The old `w` row divided by `2·(L+W)`, which needed *both* dimensions to be zero
to blow up. The new one divides by `2·L` alone — `det(MᵀM)` works out to `4L²`
— so a single mistyped parameter is enough. `!(x > 0.0f)` rather than `x <= 0.0f`
so that NaN also takes the early return. Failing to a zero velocity estimate is
safe; returning an infinity into a dead-reckoning integrator is not.

```c
    const float inv_spr = 1.0f / STEPS_PER_RAD;
    const float w_fl = f->fl * inv_spr;   /* [rad/s] */
    /* ... */
```

Undo the step conversion first, back to rad/s, so the rest of the function is
pure kinematics in physical units. `inv_spr` is a compile-time-foldable constant
expression, so this costs nothing.

```c
    const float s  = (float)MECANUM_DELTA_LEFT;
    const float d_front = w_fl - w_fr;
    const float d_rear  = w_rl - w_rr;

    v.vx = 0.25f * wheel_radius_mm * (w_fl + w_fr + w_rl + w_rr);

    v.vy = (wheel_radius_mm * s / (4.0f * wheelbase_mm))
         * ((wheelbase_mm + s * track_width_mm) * d_front
          + (wheelbase_mm - s * track_width_mm) * d_rear);

    v.w  = (wheel_radius_mm * s / (2.0f * wheelbase_mm)) * (d_front - d_rear);
```

This is the **left pseudoinverse** `(MᵀM)⁻¹Mᵀ` of the 4×3 mixing matrix — the
least-squares body motion most consistent with all four wheel speeds.

**Why it is no longer a transpose.** Under the X-drive the three matrix columns
were mutually orthogonal, `MᵀM` was diagonal, and the pseudoinverse was the
transpose with a scale factor per row — which is why the old code could be read
as "each row here is a column of the IK matrix". That shortcut is gone. The
strafe and yaw columns now have dot product `2W`, and inverting the resulting
2×2 block mixes them. Anyone porting the old code by copying its row patterns
across will get a function that is exactly right for `vx` and wrong for the
other two.

**Why it is written in axle differentials.** Expanding the algebra gives eight
per-wheel coefficients that are hard to check by eye. Grouping into

```
Δ_F = ω_FL − ω_FR      Δ_R = ω_RL − ω_RR
```

collapses it to something you can state in one sentence:

> **Yaw is the difference of the two axle differentials. Strafe is their
> weighted sum.**

Under the X-drive it was the other way round — yaw came from the side pattern,
strafe from the diagonal. The failure mode of getting them backwards is
particularly nasty because it is *silent on the axis people test first*: forward
motion is unaffected, and only strafe and yaw come out interchanged.

Three details in the code:

- `s` is `MECANUM_DELTA_LEFT`. Carrying it symbolically rather than folding the
  `-1` in means negating the handedness constants flips this function too,
  automatically and in the right direction. It costs one multiply by a
  compile-time constant.
- `track_width_mm` appears in the `vy` row but **not** in the `w` row. Yaw
  resolution is set by the wheelbase alone. A longer robot estimates its own
  rotation better; a wider one does not.
- `(wheelbase_mm - s * track_width_mm)` is `L + W = 453` for the as-built robot
  (since `s = −1`), and `(wheelbase_mm + s * track_width_mm)` is `L − W = −7`.
  The rear differential dominates `vy` by 65:1 — the mirror image of the front
  pair dominating yaw.

**Precision cost.** Reachability is unaffected: any command the IK produced
round-trips exactly. But a least-squares solve over non-orthogonal columns
amplifies per-wheel error more than an orthogonal one would — **1.44× on `vy`
and 2.03× on `w`** against the X-drive, for the same steppers. `vx` is
unaffected. Derivation §9.3 has the propagation.

**This is a command, not a measurement.** With no encoders, this reports what
the wheels were *asked* to do. Two systematic errors separate it from reality:
integer rounding at the timer peripheral, and skipped steps under load — the
latter always in the lossy direction, since a stepper can lose steps but never
gain them. Both being systematic rather than random is exactly what lets a
downstream velocity-bias loop absorb them.

---

## 5. Saturation

```c
void mecanum_clamp(wheel_rates_t *r, float max_steps_per_sec)
{
    if (r == NULL || max_steps_per_sec <= 0.0f) return;

    float peak = fabsf(r->fl);
    if (fabsf(r->fr) > peak) peak = fabsf(r->fr);
    if (fabsf(r->rl) > peak) peak = fabsf(r->rl);
    if (fabsf(r->rr) > peak) peak = fabsf(r->rr);

    if (peak > max_steps_per_sec) {
        const float s = max_steps_per_sec / peak;
        r->fl *= s;  r->fr *= s;  r->rl *= s;  r->rr *= s;
    }
}
```

**The single most important thing in this file after the matrix itself.**
Unchanged by the layout — it is pure vector scaling and knows nothing about
rollers.

The naive implementation clips each wheel independently:

```c
/* WRONG — do not do this */
if (r->fr >  max) r->fr =  max;
if (r->fr < -max) r->fr = -max;
```

That **warps the motion vector**. If FR saturates and the other three do not,
the ratio between the four wheel speeds changes, and by the forward kinematics
that is a different body velocity — a commanded pure strafe becomes an arc, and
the robot curves away from where you pointed it.

Scaling all four by one common factor preserves every ratio, so the direction of
motion is exactly preserved and only the magnitude drops. Verified in §9:
clamping the worked example to 4000 steps/s scales `vx`, `vy` and `w` all by the
identical factor 0.5702.

**What the layout changed here: which wheel saturates.** The front pair carries
essentially the whole yaw term, so whenever yaw is commanded the front wheels
reach the limit first and the clamp is triggered by one of them. Under an
X-drive both axles saturated together. The clamp itself does not care, but it
means a mixed command spends more of its range on the front motors — worth
knowing when picking `max_step_rate`.

Guarding on `max_steps_per_sec <= 0.0f` prevents a division that would produce
zero or a negative scale factor; the `peak > max` test means the common case
(nothing saturated) costs four `fabsf` calls and no writes.

---

## 6. Direction-reversal deadband

```c
void mecanum_deadband(wheel_rates_t *r, float deadband_steps_per_sec)
{
    if (r == NULL || deadband_steps_per_sec <= 0.0f) return;

    if (fabsf(r->fl) < deadband_steps_per_sec) r->fl = 0.0f;
    if (fabsf(r->fr) < deadband_steps_per_sec) r->fr = 0.0f;
    if (fabsf(r->rl) < deadband_steps_per_sec) r->rl = 0.0f;
    if (fabsf(r->rr) < deadband_steps_per_sec) r->rr = 0.0f;
}
```

The A4988 requires `DIR` to be stable for at least 200 ns before a `STEP` edge.
A wheel whose command hovers near zero will flip `DIR` back and forth as the
command dithers, producing chatter and no useful motion.

This is not hypothetical for this drivetrain: in the worked example
(`vx=200, vy=100, w=0.5`) the FL wheel comes out at **−225 steps/s** — genuinely
close to zero while the other three run in the thousands. A threshold around
20 steps/s holds it stopped instead.

**New under this layout: the rear pair deadbands during slow yaw.** Their lever
is 1.5% of the front's, so a pure yaw command below about **0.34 rad/s** puts
both rear wheels under a 20 steps/s threshold while the front pair drives
normally. That is the kinematics being obeyed, not a fault — but it looks
exactly like two dead motors to anyone who has not read this paragraph, which is
why it is also on the bench card in `TESTING.md`.

It is also the concrete reason the null-space metric is taken **before** the
deadband in `drive.c`: the deadband is a per-wheel operation and legitimately
puts energy into the null space, so measuring afterwards would make the health
metric fire on every gentle turn.

Apply this **after** `mecanum_clamp`, since clamping scales rates down and can
push a wheel into the deadband that was previously above it.

---

## 7. Null-space health check

```c
float mecanum_null_space(const wheel_rates_t *f)
{
    if (f == NULL) return 0.0f;
    return (f->fl + f->fr - f->rl - f->rr);
}
```

**This function did not change, and that is a result rather than an oversight.**

The 4×3 matrix maps 3 degrees of freedom onto 4 actuators, so it has a
one-dimensional left null space. Solving `nᵀM = 0` gives `(+1, +1, −1, −1)` —
the **front pair opposing the rear pair**. Wheel speeds in that combination
produce no body motion whatsoever; the energy goes entirely into roller scrub.

Under the X-drive the same vector spanned the null space. The derivation (§9.2)
shows why the coincidence is not one: solving `nᵀM = 0` uses only `k ≠ m`, i.e.
`W ≠ 0`, so **the same direction annihilates all three columns for either
handedness and any geometry**. Of everything in this file, the slip metric is
the one piece the layout change left entirely alone.

Verify it against the three motion patterns: forward `(+,+,+,+)` → `1+1−1−1 = 0`;
strafe `(−,+,−,+)` → `−1+1+1−1 = 0`; rotation `(−k,+k,+m,−m)` → `−k+k−m+m = 0`.
All three body motions are orthogonal to it, as they must be.

Because `mecanum_inverse` can only produce combinations of those three columns,
this function returns ~0 for any well-formed command. A non-zero result means
something **downstream** corrupted the command — per-wheel clipping instead of
common-factor scaling, a wrong `dir_invert` flag, or a stale wheel rate.

Expect small non-zero values from float rounding on large rates. Compare against
a tolerance, not against exact zero.

---

## 8. Call site

```c
wheel_rates_t cmd = mecanum_inverse(vx, vy, w,
                                    g_params.wheel_radius_mm,
                                    g_params.wheelbase_mm,
                                    g_params.track_width_mm);

mecanum_clamp(&cmd, g_params.max_steps_per_sec);
/* null-space health metric is taken HERE: post-clamp, pre-deadband */
mecanum_deadband(&cmd, g_params.deadband_steps_per_sec);

stepper_set_rate(MOTOR_FL, cmd.fl);   /* sign -> DIR, |value| -> STEP */
stepper_set_rate(MOTOR_FR, cmd.fr);
stepper_set_rate(MOTOR_RL, cmd.rl);
stepper_set_rate(MOTOR_RR, cmd.rr);

/* Dead reckoning gets the POST-clamp, POST-deadband rates. */
body_vel_t est = mecanum_forward(&cmd,
                                 g_params.wheel_radius_mm,
                                 g_params.wheelbase_mm,
                                 g_params.track_width_mm);
```

In this firmware that sequence lives in `drive_solve()` (`main/drive.c`) so no
call site has to remember it. Order matters in four places:

1. **Clamp before deadband.** Scaling can move a wheel into the deadband.
2. **Null space between the two.** The clamp preserves it (all four wheels scale
   equally); the deadband does not.
3. **Clamp before forward kinematics.** Passing the pre-clamp command into dead
   reckoning is the classic open-loop drift bug — the estimator integrates a
   velocity the hardware never produced, and the error compounds silently for as
   long as you stay saturated.
4. **Motor mirroring lives inside `stepper_set_rate`.** The left-side motors are
   physically mirrored, so realising a positive `ω` needs the opposite `DIR`
   level from the right side. Handle that with a per-wheel `dir_invert` flag in
   the GPIO layer. Putting it in the matrix instead would break the FK
   round-trip and every other motion involving that wheel.

---

## 9. Verification

Real output from the shipped source, `wheel_radius_mm=30`, `wheelbase_mm=223`,
`track_width_mm=230`:

```
A pure forward vx=200    FL=  3395.305 FR=  3395.305 RL=  3395.305 RR=  3395.305 | FK=(200.0000, -0.0000, -0.0000) | null=0.000000
B strafe left vy=200     FL= -3395.305 FR=  3395.305 RL= -3395.305 RR=  3395.305 | FK=(0.0000, 200.0000, -0.0000) | null=0.000000
C rotate CCW w=1.0       FL= -3845.183 FR=  3845.183 RL=   -59.418 RR=    59.418 | FK=(0.0000, 0.0000, 1.0000) | null=0.000000
D combined               FL=  -224.939 FR=  7015.550 RL=  1667.944 RR=  5122.667 | FK=(200.0000, 100.0000, 0.5000) | null=0.000000

diagonal vx=vy=200       FL=     0.000 FR=  6790.611 RL=     0.000 RR=  6790.611
anti-diag vx=-vy=200     FL=  6790.611 FR=     0.000 RL=  6790.611 RR=     0.000
clamped to 4000 steps/s  FL=  -128.252 FR=  4000.000 RL=   950.998 RR=  2920.750 | FK=(114.032, 57.016, 0.2851)
  ratios vs unclamped: vx 0.5702  vy 0.5702  w 0.5702   (per-wheel 0.5702 0.5702 0.5702 0.5702)

yaw levers: FL=-226.5 FR=226.5 RL=-3.5 RR=3.5 mm   front:rear = 64.71:1
```

Line C is the one to look at. Under an X-drive all four wheels read ±3845; here
the rear pair reads ±59. **If a build shows ±3845 on all four, it is still
running the old kinematics.**

Properties worth keeping as unit tests — all of these are in
`test/test_kinematics.c`, and the firmware re-runs the first three at boot:

| Test | Property |
|---|---|
| **IK → FK round trip, per axis** | `vx`, `vy` and `w` each separately must come back unchanged. Per-axis rather than combined, because a rank-deficient layout fails only one of them. |
| **Side idles, both directions** | `vx = vy` leaves FL and RL at exactly 0; `vx = -vy` leaves FR and RR at 0. Running both is what separates "handedness correct" from "handedness mirrored". |
| **Null space is zero** | Any output of `mecanum_inverse` must give ~0. Catches command corruption. |
| **Clamp preserves direction** | `vx`, `vy` and `w` must all scale by the *same* factor. Catches per-wheel clipping creeping back in. |
| **Lever ratio** | `\|κ_F/κ_R\| = 64.71` on this frame. Catches a partially-applied layout change, which would otherwise pass the round trip. |
| **Column non-orthogonality** | `c_vy · c_w = 2W = 460`. Asserts the layout is what the FK closed form assumes. |

The **side test is the most useful one to run on the physical robot**: command
`vx = vy` and confirm both left wheels are genuinely stationary, then `vx = -vy`
and confirm both right wheels are. Two adjacent wheels standing still while
their neighbours drive is unambiguous across a bench — easier to see than the
X-drive's diagonal pair was — and it fails loudly if the roller handedness is
mirrored from what the matrix assumes.

**One hardware limit visible in case D:** FR at 7016 microsteps/s is 2.19 rev/s
≈ 131 RPM. The A4988 emits that pulse rate without difficulty, but a NEMA17 on a
12 V rail is well off its torque curve there, and skipped steps become likely.
Case D sits near the practical ceiling of this build — worth setting
`max_steps_per_sec` with that in mind rather than at the driver's electrical
limit. The peak wheel is a front wheel under either layout.

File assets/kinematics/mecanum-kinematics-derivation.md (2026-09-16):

# Mecanum Kinematics — Full Symbolic Derivation

**Project:** OMNIS · 4-wheel holonomic mecanum platform
**Layout:** **lateral parallel rollers** — left pair alike, right pair mirrored
**Scope:** Complete first-principles derivation of the inverse and forward
kinematics for the OMNIS drivetrain, kept fully symbolic in
`wheel_radius_mm`, `wheelbase_mm`, and `track_width_mm`.

> This file is the *why*. For the equations alone (no derivation), see
> [`mecanum-kinematics-reference.md`](mecanum-kinematics-reference.md).
> For the firmware, see [`mecanum_kinematics.c`](mecanum_kinematics.c) and
> [`mecanum-kinematics-code-explained.md`](mecanum-kinematics-code-explained.md).

> **This document was re-derived in full when the wheel layout changed.** The
> drivetrain is no longer a textbook X-drive. Everything below describes the
> as-built machine; §13 records what the change did and did not move, for
> anyone holding an older printout.

---

## 1. Hardware assumptions

These are the physical facts the derivation rests on. If any of them change,
the affected section is flagged inline.

| Property | Value | Affects |
|---|---|---|
| Wheel type | 60 mm mecanum, rollers at **45°** to the wheel plane | §5 — the 45° is what makes the mixing coefficients clean ±1 |
| Layout | 4 wheels, rectangular, all axles parallel to the body Y axis | §3, §5 |
| **Roller handedness** | **left pair (FL, RL) share one tilt; right pair (FR, RR) share the mirrored tilt** | **§5, §6, §8 — this is the one that changed** |
| Motor | 2-phase NEMA17-class, 200 full steps/rev (1.8°/step) | §7 |
| Driver | A4988, **fixed** 1/16 microstepping (MS1/MS2/MS3 tied HIGH) | §7 |
| Resulting resolution | 200 × 16 = **3200 microsteps/rev** | §7 |
| Feedback | **None** — open-loop steppers, no encoders | §9 |

The handedness row is the change. It was forced by mounting-shaft and motor
constraints, not chosen, and it is why this document exists in a second
edition. Viewed from above with the robot facing up the page:

```
        FL  /                 \  FR
        RL  /                 \  RR
```

The microstepping figure is a hard-wired constant, not a runtime parameter.
The three geometry values are runtime parameters read from `params.json` and
must never be baked into the equations.

---

## 2. Coordinate and sign conventions

Right-handed body frame, standard robotics convention (ROS REP-103):

| Symbol | Quantity | Positive direction | Unit |
|---|---|---|---|
| `vx` | body longitudinal velocity | **forward** | mm/s |
| `vy` | body lateral velocity (strafe) | **left** | mm/s |
| `w` (ω) | body yaw rate | **counter-clockwise**, viewed from above | rad/s |
| `ω_i` | angular velocity of wheel *i* | the sense that drives the robot **forward** | rad/s |
| `f_i` | step-pulse rate for wheel *i* | sign follows `ω_i` | microsteps/s |

### Drawing convention for roller tilt

Roller tilt is stated throughout as a `/` or `\` glyph. That glyph is the
**roller's axis of rotation**, projected into the ground plane, seen from
**above**, with the robot facing **up the page** and body **+y to the
page-left**. It is what you actually see looking down at the top roller of an
assembled wheel.

Two conventions are possible and they are mirror images, so this one is fixed
here, once, and §5.3 gives the bench test that confirms it on hardware.

### Unit discipline

`wheel_radius_mm`, `wheelbase_mm`, and `track_width_mm` are in **millimetres**,
so `vx` and `vy` must also be in **mm/s**. Yaw rate `w` is in **rad/s**, which
makes the product `(length in mm) × (rad/s)` come out in mm/s — dimensionally
consistent with `vx` and `vy`.

Feeding m/s into these equations produces a yaw contribution that is wrong by a
factor of 1000 while forward motion still looks correct — a failure mode that
only shows up once you command rotation. Normalise units at the RC input layer,
once, and never again.

### Wheel angular velocity is a *mathematical* sign

`ω_i > 0` means "this wheel is turning in the sense that pushes the robot
forward". It is **not** a statement about phase order on the motor. The left-side
motors are physically mirrored relative to the right-side motors, so realising
`ω_i > 0` on FL and FR generally requires opposite `DIR` pin levels. That
mirroring belongs in the GPIO layer as a per-wheel invert flag — see §10.

---

## 3. Wheel positions in the body frame

Origin at the geometric centre of the four wheel contact patches.
`wheelbase_mm` is the front-to-back wheel-centre distance; `track_width_mm` is
the left-to-right wheel-centre distance.

```
                    +x (forward)
                        ^
                        |
        FL  o───────────┼───────────o  FR
           /│           |           │\
          / │           |           │ \    wheelbase_mm
  +y <───/──┼───────────O           │  \   = front-to-back
  (left)/   │                       │   \
       /    │                       │    \
        RL  o───────────────────────o  RR
           /<────── track_width_mm ─────>\
                    (left-to-right)

  the / and \ marks are the roller tilts: both left wheels alike,
  both right wheels alike, mirrored across the centreline
```

So:

```
x_FL = +wheelbase_mm/2      y_FL = +track_width_mm/2
x_FR = +wheelbase_mm/2      y_FR = -track_width_mm/2
x_RL = -wheelbase_mm/2      y_RL = +track_width_mm/2
x_RR = -wheelbase_mm/2      y_RR = -track_width_mm/2
```

Compactly: `x_i = ±wheelbase_mm/2` (front positive),
`y_i = ±track_width_mm/2` (left positive).

Throughout, `L = wheelbase_mm` and `W = track_width_mm`.

---

## 4. Step 1 — velocity of each wheel's contact patch

For a rigid body moving in a plane, the velocity of a point at body-frame
position `r_i = (x_i, y_i)` is the body translation plus the rotational
contribution:

```
v_i = v_body + (w * ẑ) × r_i
```

Expanding the cross product with `ẑ = (0, 0, 1)`:

```
(w * ẑ) × (x_i, y_i, 0) = w * (-y_i, x_i, 0)
```

Therefore the contact patch of wheel *i* moves at:

```
v_i = ( vx - w*y_i ,  vy + w*x_i )                              ... (4.1)
```

Sanity check on the signs: a wheel on the **left** (`y_i > 0`) under
counter-clockwise rotation (`w > 0`) gets a **negative** x-component — it moves
backward. That is correct for a left turn.

Note (4.1) contains no wheel-specific physics yet. It is pure rigid-body
mechanics and would be identical for any wheel type. **This section is
completely untouched by the layout change** — the rollers enter in §5.

---

## 5. Step 2 — the mecanum roller constraint

This is where the wheel type enters, and where the layout change bites.

A conventional wheel imposes two constraints: it rolls along its heading and
cannot slide sideways. A mecanum wheel relaxes the second one. Its rim carries
free-spinning rollers mounted at 45°, so the contact patch **can** slide freely
in one direction — perpendicular to the roller's own axis.

The consequence: the wheel only transmits force along the **roller axis
direction**. Motion perpendicular to that axis is unconstrained, absorbed by the
roller spinning on its own bearing.

### 5.1 The constraint equation

Let `â_i` be the unit vector along wheel *i*'s roller axis, projected into the
ground plane. With rollers at 45° to the wheel plane, and the wheel heading
along the body `x̂` axis:

```
â_i = (1/√2) * (1, δ_i)          where  δ_i = ±1                ... (5.1)
```

`δ_i` is the **roller handedness** of that wheel — the sign that distinguishes
the two mirrored roller tilts:

```
δ = +1   ->  axis along the forward-LEFT  diagonal  ->  drawn "\"
δ = -1   ->  axis along the forward-RIGHT diagonal  ->  drawn "/"
```

The no-slip condition applies only along `â_i`: the component of the contact
velocity in that direction must equal the component the wheel's own rotation
produces in that direction. The wheel rim drives along `x̂` at speed
`wheel_radius_mm * ω_i`, so:

```
v_i · â_i  =  (wheel_radius_mm * ω_i) * (x̂ · â_i)               ... (5.2)
```

### 5.2 Why 45° gives clean ±1 coefficients

Substituting (4.1) and (5.1) into (5.2):

```
(1/√2) * [ (vx - w*y_i) + δ_i * (vy + w*x_i) ]
        =  wheel_radius_mm * ω_i * (1/√2)
```

The `1/√2` appears on **both** sides and cancels exactly. This cancellation is
the entire reason mecanum mixing matrices contain only `+1` and `-1` and no
trigonometric constants — it is a property of the 45° roller angle specifically.
A wheel with rollers at any other angle would leave a `tan` factor on the `vy`
and `w` terms.

Cancelling and rearranging:

```
wheel_radius_mm * ω_i  =  vx  +  δ_i*vy  +  w*(δ_i*x_i - y_i)   ... (5.3)
```

Equation (5.3) is the general per-wheel result, and it is **layout-independent**:
it holds for an X-drive, for this parallel layout, or for any other assignment
of the four `δ_i`. Everything specific to OMNIS is now in one place — which
four signs go into `δ`. The firmware mirrors that structure exactly:
`MECANUM_DELTA_FL` … `MECANUM_DELTA_RR` in
[`mecanum_kinematics.h`](mecanum_kinematics.h) are the only statement of the
layout, and (5.3) is implemented literally.

### 5.3 Assigning handedness to wheels — the as-built layout

The physical pairing is: **both left wheels share one roller tilt; both right
wheels share the mirrored tilt.** The wheels are `/` on the left and `\` on
the right, which by the convention in §2 and §5.1 gives:

> ### Sign assignment
> **FL and RL take `δ = -1`** — roller axis `â = (1, -1)/√2`, along the
> forward-right diagonal, drawn `/`. These take the **negative** sign on `vy`.
>
> **FR and RR take `δ = +1`** — roller axis `â = (1, +1)/√2`, along the
> forward-left diagonal, drawn `\`. These take the **positive** sign on `vy`.

This is **not** the textbook X-drive, in which the shared tilts run along the
diagonals (FL with RR, FR with RL). The difference is exactly the rear pair:
FL and FR are assigned as they always were, and RL and RR have swapped.
Consequently **every front-wheel equation in this document is unchanged from
the previous edition, and every rear-wheel equation is different.** That is a
useful thing to check when reviewing a port.

#### If the hardware turns out to be mirrored

Two conventions for reading a roller glyph exist and they are mirror images.
This document fixes one (§2) and derives everything from it consistently, but
consistency is not the same as being right about the hardware, and the
difference is not academic: it flips the direction the robot strafes.

**The bench test that settles it, in one command:**

> Command `vx = vy` (equal forward and left, no yaw), wheels off the ground.
>
> - **Both LEFT wheels dead still**, both right wheels driving → handedness is
>   correct as written.
> - **Both RIGHT wheels dead still** instead → the handedness is mirrored.
>   Negate all four `MECANUM_DELTA_*` constants together and rebuild.
> - **A diagonal pair still** (FL and RR, or FR and RL) → the wheels are not in
>   the parallel layout at all; this document does not describe your robot.
> - **Anything else** → a `DIR` invert flag is wrong. Fix plain forward motion
>   before looking at anything here.

Negate all four `δ` **together**. Every sign in the `vy` **and** `w` columns
flips together — they are not independent, because both derive from the same
`δ_i` in (5.3). Do not flip one column by hand, and do not "fix" a wrong strafe
direction with a `dir_invert` flag: that would break forward motion and the FK
round trip along with it.

### 5.4 The yaw coefficient no longer collapses to a single lever arm

The yaw term in (5.3) is `κ_i = δ_i*x_i - y_i`. Substituting positions from §3
and handedness from §5.3:

```
FL:  δ=-1, x=+L/2, y=+W/2   ->  (-1)(+L/2) - (+W/2)  =  -(L + W)/2
FR:  δ=+1, x=+L/2, y=-W/2   ->  (+1)(+L/2) - (-W/2)  =  +(L + W)/2
RL:  δ=-1, x=-L/2, y=+W/2   ->  (-1)(-L/2) - (+W/2)  =  +(L - W)/2
RR:  δ=+1, x=-L/2, y=-W/2   ->  (+1)(-L/2) - (-W/2)  =  -(L - W)/2
```

**This is the heart of the change.** Under an X-drive all four came out at
`±(L+W)/2` — one lever arm, one symbol `k`, four signs. Here the two axles get
**different lever arms**:

```
k = (L + W)/2          front pair, "long" lever               ... (5.4a)
m = (L - W)/2          rear pair,  "short" lever              ... (5.4b)
```

so `κ_FL = -k`, `κ_FR = +k`, `κ_RL = +m`, `κ_RR = -m`.

Three properties of `k` and `m` are worth naming, because they carry most of
what is different about driving this machine:

**(a) The rear lever is small, and on OMNIS it is tiny.** With `L = 223` and
`W = 230`, `k = 226.5 mm` and `m = -3.5 mm`. The front axle's lever is **64.7×**
the rear's, so the front pair supplies **98.5%** of the yaw authority. During a
pure spin the rear wheels barely turn (§11 Case C) — the rotation is absorbed
almost entirely by the rear rollers scrubbing. This is correct behaviour and
not a fault; it is also the reason a slow yaw command will deadband the rear
pair while the front pair still drives.

**(b) The rear lever changes sign at a square chassis.** `m = (L-W)/2` is
negative when the frame is wider than it is long, positive when it is longer,
and exactly zero when `L = W`. OMNIS sits 3.5 mm from that crossover. Nothing
in the mathematics misbehaves there — the term simply passes through zero, and
§8 shows the matrix stays full-rank regardless — but **do not build an
intuition about which way the rear wheels turn during a spin.** It is not a
robust fact about the machine.

**(c) Two identities that do the algebraic work later.** They hold for any
geometry and are what make §8 come out in closed form:

```
k + m = L          (the two levers sum to the wheelbase)
k - m = W          (and differ by the track width)
```

The X-drive's lesson that "only the sum `L + W` matters, never either dimension
alone" is **no longer true**. Both dimensions now appear separately, and the
wheelbase in particular acquires a role it did not have before — §8 finds it
alone in the yaw scale factor.

---

## 6. Inverse kinematics — the wheel-speed mixing matrix

Substituting (5.4) and the handedness assignment into (5.3), and dividing
through by `wheel_radius_mm`:

```
                  ┌                       ┐
 ┌      ┐         │   1     -1     -k     │   ┌      ┐
 │ ω_FL │         │                       │   │  vx  │
 │ ω_FR │    1    │   1     +1     +k     │   │  vy  │
 │ ω_RL │  = ───  │                       │ · │   w  │
 │ ω_RR │    r    │   1     -1     +m     │   └      ┘
 └      ┘         │                       │
                  │   1     +1     -m     │
                  └                       ┘

        r = wheel_radius_mm
        k = (wheelbase_mm + track_width_mm) / 2
        m = (wheelbase_mm - track_width_mm) / 2
```

Written out:

```
ω_FL = ( vx - vy - k*w ) / wheel_radius_mm
ω_FR = ( vx + vy + k*w ) / wheel_radius_mm
ω_RL = ( vx - vy + m*w ) / wheel_radius_mm
ω_RR = ( vx + vy - m*w ) / wheel_radius_mm
```

The matrix has three columns and four rows: three degrees of freedom driving
four actuators. It is over-determined, which is the formal reason a mecanum
platform can fight itself (§9.2).

### 6.1 Motion-by-motion check

Each row below is obtained by setting one input non-zero and reading off the
matrix column.

| Motion | Input | FL | FR | RL | RR | Split | Notes |
|---|---|---|---|---|---|---|---|
| Forward | `vx > 0` | + | + | + | + | none | all four identical |
| Strafe **left** | `vy > 0` | **−** | **+** | **−** | **+** | **sides** | all four equal magnitude |
| Rotate **CCW** | `w > 0` | **−** | **+** | **−** | **+** | **sides** | front pair 64.7× faster than rear |
| Diagonal fwd-left | `vx = vy > 0` | **0** | + | **0** | + | — | the whole **left side** idles |
| Diagonal fwd-right | `vx = -vy > 0` | + | **0** | + | **0** | — | the whole **right side** idles |

Two things to take from this table.

**Strafe and yaw now share a sign pattern.** Both split along the sides,
`(−,+,−,+)`. Under an X-drive they were cleanly distinguishable — strafe split
along the diagonals, rotation along the sides — and "which pattern is this?"
was enough to identify a motion by eye. Here the two are told apart only by the
*ratio* between the front and rear magnitudes: equal for strafe, 64.7:1 for
yaw. §8 shows this is not merely cosmetic — the two columns are genuinely
non-orthogonal, at 44° rather than 90°.

**The diagonal test is now a side test, and there are two of them.** Commanding
`vx = vy` leaves both left wheels exactly stationary; `vx = -vy` leaves both
right wheels stationary. Running *both* is what distinguishes a correct
handedness assignment from a mirrored one (§5.3) — a mirrored build passes one
and fails the other. Two adjacent wheels standing still while their neighbours
drive is also easier to see across a bench than a diagonal pair was.

---

## 7. Step-pulse frequency conversion

Unaffected by the layout change — this stage knows nothing about rollers.

The A4988 is hard-wired to 1/16 microstepping, so:

```
MICROSTEPS_PER_REV = 200 full steps/rev × 16 = 3200 microsteps/rev
```

One revolution is `2π` radians, so the conversion from angular velocity to
pulse rate is a single constant:

```
f_i = ω_i * ( MICROSTEPS_PER_REV / (2*π) )

    = ω_i * ( 3200 / 6.283185307... )

    = ω_i * 509.29581789...              [microsteps/s per rad/s]   ... (7.1)
```

Combining (6) and (7.1) directly, the full input-to-pulse-rate chain is:

```
f_FL = ( vx - vy - k*w ) * 509.295818 / wheel_radius_mm
f_FR = ( vx + vy + k*w ) * 509.295818 / wheel_radius_mm
f_RL = ( vx - vy + m*w ) * 509.295818 / wheel_radius_mm
f_RR = ( vx + vy - m*w ) * 509.295818 / wheel_radius_mm
```

`sign(f_i)` drives the A4988 `DIR` pin. `|f_i|` is the `STEP` pulse rate.

The 509.295818 constant is derived, not measured — it is exact given the
microstepping and motor step angle, and changes only if the microstepping
jumpers or the motor are changed.

---

## 8. Forward kinematics — commanded-velocity estimate

### 8.1 Why a pseudoinverse, and why it got harder

The mixing matrix `M` is 4×3. It maps 3 body velocities to 4 wheel speeds, so
it has no ordinary inverse. Recovering body velocity from wheel speeds requires
the **left pseudoinverse** `M⁺ = (MᵀM)⁻¹Mᵀ`, which yields the least-squares
best fit — the body motion most consistent with all four wheel speeds at once.

Under the X-drive this was nearly free: the three columns were mutually
orthogonal, `MᵀM` was diagonal, and `M⁺` came out as a scaled transpose. **That
shortcut is gone.** Writing the columns as

```
c_vx = (1, 1, 1, 1)/r
c_vy = (-1, +1, -1, +1)/r
c_w  = (-k, +k, +m, -m)/r
```

the `vx` column is still orthogonal to both others — `c_vx · c_vy = 0` and
`c_vx · c_w = -k + k + m - m = 0` — but the other pair is not:

```
c_vy · c_w  =  [ (-1)(-k) + (+1)(+k) + (-1)(+m) + (+1)(-m) ] / r²

            =  2(k - m) / r²  =  2W / r²                        ... (8.1)
```

using the identity `k - m = W` from §5.4(c). **The strafe and yaw columns
overlap by exactly twice the track width**, and that is the algebraic signature
of the whole layout change. It vanishes only for `W = 0`, which is not a robot.

So:

```
        ┌                          ┐
        │  4      0        0       │
MᵀM  =  │  0      4       2W       │ / r²
        │  0     2W    2(k² + m²)  │
        └                          ┘
```

and `2(k² + m²) = L² + W²`, since `k² + m² = [(L+W)² + (L-W)²]/4 = (L² + W²)/2`.

### 8.2 Inverting the 2×2 block

The `vx` row decouples immediately; the `vy` and `w` rows need the 2×2 block

```
        ┌            ┐
   B =  │  4     2W  │          det B = 4(L² + W²) - 4W² = 4L²     ... (8.2)
        │ 2W   L²+W² │
        └            ┘
```

**The determinant is `4L²`** — the track width cancels completely. Three
consequences follow directly, and they are the most useful results in this
document:

1. **The layout is holonomic for every real robot.** `det B = 0` only if
   `L = 0`. There is no chassis aspect ratio, square included, at which this
   drivetrain loses a degree of freedom. The near-singular look of a square
   frame (§5.4b, where `m → 0`) is an illusion: the rear pair stops
   contributing to *yaw*, but it still contributes to `vy`, and rank is
   preserved.
2. **Yaw resolution is set by the wheelbase alone.** Not by `L + W`, as under
   the X-drive. A longer robot estimates its own rotation better; a wider one
   does not.
3. It is why §8.3 comes out in closed form at all, with no matrix arithmetic
   at runtime.

Inverting and multiplying by `Mᵀ` (the algebra is mechanical; the result was
checked against an exact rational pseudoinverse — see §8.4):

### 8.3 The result

State it in terms of the two **axle differentials**, which is where it is
cleanest:

```
Δ_F = ω_FL - ω_FR          front differential
Δ_R = ω_RL - ω_RR          rear  differential
```

```
vx = (wheel_radius_mm / 4) * ( ω_FL + ω_FR + ω_RL + ω_RR )

vy = (wheel_radius_mm / (4*wheelbase_mm))
            * ( (track_width_mm - wheelbase_mm) * Δ_F
              - (track_width_mm + wheelbase_mm) * Δ_R )

w  = (wheel_radius_mm / (2*wheelbase_mm)) * ( -Δ_F + Δ_R )
```

Or fully expanded, one coefficient per wheel:

```
vy = (r / (4L)) * ( (W-L)*ω_FL - (W-L)*ω_FR - (L+W)*ω_RL + (L+W)*ω_RR )

w  = (r / (2L)) * (   -ω_FL    +     ω_FR   +     ω_RL   -      ω_RR )
```

Read the shape of it:

> **Yaw is the difference of the two axle differentials. Strafe is their
> weighted sum.**

Under the X-drive it was the other way round — yaw came from the side-sum
difference and strafe from the diagonal pattern. The two forms look alike
enough that swapping them is the single most likely error when porting older
code, and it is silent: forward motion still works perfectly, and only strafe
and yaw come out interchanged. The round-trip test in §8.4 catches it
immediately, which is why it is worth keeping as a unit test.

Also note what is **not** in the `w` row: `track_width_mm`. The yaw estimate is
built from the wheelbase alone, per §8.2(2).

Converting from step rates back to angular velocity inverts (7.1):

```
ω_i = f_i * (2*π / 3200) = f_i / 509.295818
```

### 8.4 Verification

Two independent checks, both mechanical rather than by eye:

- **Against an exact pseudoinverse.** The closed form above was compared with
  `(MᵀM)⁻¹Mᵀ` computed in exact rational arithmetic, for **both** handedness
  signs and four geometries (223×230, 300×200, 250×250 square, 100×400). Every
  coefficient matched exactly, with no floating point in the comparison.
- **Round trip.** Feeding the §11 worked example through IK and then FK
  reproduces `(vx, vy, w) = (200.0, 100.0, 0.5)`. Any sign error fails this, and
  `test/test_kinematics.c` runs it on every build along with a per-axis round
  trip for `vx`, `vy` and `w` separately — three separate tests, because a
  rank-deficient layout would fail only one of them.

---

## 9. Open-loop considerations

### 9.1 This is a command, not a measurement

With no encoders, §8 tells you what the wheels were **asked** to do. Two error
sources separate that from reality, and both are systematic rather than random:

1. **Integer rounding** of `f_i` at the timer/RMT peripheral. The hardware can
   only emit whole pulses at whole timer ticks, so the realised rate is
   quantised. The error is small but *biased* — it accumulates rather than
   averaging out.
2. **Skipped steps** under acceleration or load. Critically, this error is
   always in one direction: the wheel can lose steps but never gain them. Real
   motion is always ≤ commanded, never more.

Both are systematic, which is exactly what a downstream velocity-bias loop can
estimate and absorb. Random noise could not be corrected this way; a consistent
bias can.

### 9.2 The unobservable mode — unchanged by the layout

The 4×3 matrix has a one-dimensional left null space. Solving `nᵀM = 0`:

- `n · c_vx = 0` and `n · c_vy = 0` together force `n₃ = -n₁` and `n₄ = -n₂`.
- `n · c_w = 0` then reduces to `(k - m)(n₁ - n₂) = W(n₁ - n₂) = 0`, so
  `n₁ = n₂`.

giving the unique direction (up to scale):

```
(+ω_FL + ω_FR - ω_RL - ω_RR)
```

That is the **front pair opposing the rear pair**. It produces **no body motion
at all** — any energy put into this combination goes entirely into roller scrub
and tyre slip.

**This is identical to the X-drive's null space**, and that is not a
coincidence worth shrugging at: the derivation above used only `k ≠ m`, i.e.
`W ≠ 0`. The same vector annihilates all three columns **for either handedness
and for any geometry**. Of everything in this document it is the one result the
layout change left completely alone, so `mecanum_null_space()` needed no edit
and the health metric keeps its meaning.

Check it against the three motion columns: forward `(+,+,+,+)` gives
`1+1-1-1 = 0`; strafe `(-,+,-,+)` gives `-1+1+1-1 = 0`; rotation `(-k,+k,+m,-m)`
gives `-k+k-m+m = 0`. All three body motions are orthogonal to it, as they must
be.

Because the IK in §6 never generates a non-zero value for it, computing it on
the commanded step rates should always yield zero. If it does not, something
downstream — a clamp applied per-wheel, a saturated axis, a wrong invert flag —
has corrupted the command, and the drivetrain is fighting itself.

### 9.3 What the layout costs: conditioning

This section has no X-drive counterpart, because under the X-drive there was
nothing to say: orthogonal columns cost nothing.

**The strafe and yaw columns meet at 44°, not 90°.** From (8.1):

```
cos θ = (c_vy · c_w) / (|c_vy| |c_w|)
      = 2W / (2 * sqrt(L² + W²))
      = W / sqrt(L² + W²)
      = 230 / 320.36 = 0.7179        ->  θ = 44.1°
```

Note this depends only on the frame's aspect ratio, not on the wheels.

**What that does and does not affect.** It does *not* affect the IK: any
`(vx, vy, w)` is still reachable exactly, and — worth stating plainly, because
it is the first thing people assume was lost — **the peak wheel rate per unit
of commanded motion is unchanged on all three axes.** The same step-rate ceiling
buys the same top speed, the same strafe speed, and the same yaw rate as before.
The layout costs nothing in performance.

What it costs is **precision in the estimate**. The least-squares solution
amplifies per-wheel error more than an orthogonal one would. Taking independent
per-wheel error `σ` and propagating through the §8.3 rows:

| Estimate | X-drive error gain | This layout | Ratio |
|---|---|---|---|
| `vx` | 15.00 | 15.00 | **1.00×** |
| `vy` | 15.00 | 21.55 | **1.44×** |
| `w` | 0.0662 | 0.1345 | **2.03×** |

So dead reckoning drifts about 1.4× faster laterally and about 2× faster in
heading, for the same stepper behaviour. On a robot with no encoders and a
§9.1 error budget that is already dominated by skipped steps, this is a real
but second-order cost — worth knowing before trusting a long open-loop
trajectory, not worth redesigning the chassis over.

**Where it does bite harder: disturbance rejection.** Two wheel patterns that
are 44° apart are, by that much, harder to tell apart. A wheel-speed error
whose shape resembles the strafe pattern will be partly read as yaw and vice
versa. There is no estimator here to be fooled today, but if one is ever added,
this is the coupling it will have to deal with — and the reason `L` appears
alone in §8.3 is worth remembering there: **a longer wheelbase directly improves
yaw conditioning.**

---

## 10. What lives where

The derivation above is deliberately free of hardware quirks. Keep it that way:

| Concern | Belongs in | Never in |
|---|---|---|
| Roller handedness | the four `MECANUM_DELTA_*` constants, negated **together** | anywhere else |
| Motor phase mirroring (left vs right side) | GPIO layer, per-wheel `dir_invert` flag | the mixing matrix |
| RC stick polarity | RC input mapping layer | the mixing matrix |
| Speed limits / saturation | a **common-factor** scale applied to all four wheels | per-wheel clipping |
| Geometry values | `params.json`, passed as function arguments | compile-time constants |

The reason the first row matters: the handedness constants and the yaw levers
are not independent quantities that happen to agree — the levers are *computed
from* the handedness, in `mecanum_yaw_levers()`. Changing one without the other
is not expressible in this code, which is the point.

The reason the second row matters: flipping a sign in the mixing matrix to fix a
motor that spins backwards will appear to work for that one motion and will
silently break the FK round-trip and every other motion involving that wheel.

The reason the fourth row matters: clipping wheels individually **warps the
motion vector**. If FR saturates and the others do not, the commanded strafe
becomes an arc. Scaling all four by one common factor preserves the direction of
motion and only reduces its magnitude.

---

## 11. Worked numeric example — actual OMNIS build

```
wheel_radius_mm = 30
wheelbase_mm    = 223
track_width_mm  = 230

k             = (223 + 230) / 2 =  226.5 mm      front yaw lever
m             = (223 - 230) / 2 =   -3.5 mm      rear  yaw lever
|k / m|                         =  64.71         front:rear yaw authority
STEPS_PER_RAD = 3200 / (2π)     = 509.295818
k / r         = 226.5 / 30      = 7.55   rad/s of front-wheel speed per rad/s of yaw
m / r         =  -3.5 / 30      = -0.1167 rad/s of rear-wheel speed per rad/s of yaw
```

### Case A — pure forward, `vx = 200 mm/s`

| Wheel | ω (rad/s) | f (µsteps/s) |
|---|---|---|
| FL | +6.66667 | +3395.305 |
| FR | +6.66667 | +3395.305 |
| RL | +6.66667 | +3395.305 |
| RR | +6.66667 | +3395.305 |

Identical to the X-drive: forward motion never involved the rollers' handedness.

### Case B — pure strafe left, `vy = 200 mm/s`

| Wheel | ω (rad/s) | f (µsteps/s) |
|---|---|---|
| FL | −6.66667 | −3395.305 |
| FR | +6.66667 | +3395.305 |
| RL | −6.66667 | −3395.305 |
| RR | +6.66667 | +3395.305 |

Left side back, right side forward — the pattern that would be a *spin* on a
differential-drive robot, and was a *diagonal* pattern under the X-drive. All
four magnitudes are equal, which is what distinguishes this from Case C.

Strafe costs the **same** wheel speed as forward motion for the same body speed,
exactly as before. It nonetheless feels weaker, because only the roller-axis
component of each wheel's force reaches the floor — a force effect, not a
kinematics error.

### Case C — pure rotation CCW, `w = 1.0 rad/s`

| Wheel | ω (rad/s) | f (µsteps/s) |
|---|---|---|
| FL | −7.55000 | −3845.183 |
| FR | +7.55000 | +3845.183 |
| RL | **−0.11667** | **−59.418** |
| RR | **+0.11667** | **+59.418** |

**The signature of this layout.** The front wheels spin at `k/r = 7.55 rad/s`
as they always did; the rear wheels crawl at 1.5% of that. If a bench test shows
all four at 3845, the build is still running X-drive kinematics.

At the usual 20 steps/s deadband, the rear pair is held stopped for any
commanded yaw below about **0.34 rad/s** while the front pair drives normally.
That is correct, and worth writing on the bench card before someone reports it
as a dead motor.

### Case D — combined, `vx = 200`, `vy = 100`, `w = 0.5`

`k*w = +113.25 mm/s`,  `m*w = -1.75 mm/s`

| Wheel | Arithmetic | ω (rad/s) | f (µsteps/s) | DIR |
|---|---|---|---|---|
| FL | (200 − 100 − 113.25)/30 | −0.441667 | **−224.939** | reverse |
| FR | (200 + 100 + 113.25)/30 | +13.775000 | **+7015.550** | forward |
| RL | (200 − 100 − 1.75)/30 | +3.275000 | **+1667.944** | forward |
| RR | (200 + 100 + 1.75)/30 | +10.058333 | **+5122.667** | forward |

FK round-trip: `(200.0, 100.0, 0.5)` ✓
Null-space check: `(−224.939) + 7015.550 − 1667.944 − 5122.667 = 0.000` ✓

Three practical observations from this case:

- FR at 7016 µsteps/s is **2.19 rev/s ≈ 131 RPM**. The A4988 handles that pulse
  rate without difficulty, but a NEMA17 on a 12 V rail has fallen well off its
  torque curve by then. Case D sits near the practical ceiling of this build.
  Unchanged from the X-drive: the peak wheel is a front wheel either way.
- FL at −225 µsteps/s is close to zero and will **chatter across the direction
  reversal** as the command dithers. See the deadband note in the reference
  document.
- The **rear pair spread is much narrower than the front pair's** (1668 to 5123
  against −225 to 7016), because only the front pair carries the yaw term in any
  meaningful amount. Under an X-drive the two axles saturated together; here the
  front pair reaches the clamp first whenever yaw is commanded, and the
  common-factor clamp then scales the whole command.

### Case E — the handedness bench test

`vx = vy = 200 mm/s` (diagonal forward-left):

| Wheel | f (µsteps/s) |
|---|---|
| FL | **0.000** |
| FR | +6790.611 |
| RL | **0.000** |
| RR | +6790.611 |

and its mirror, `vx = 200`, `vy = -200` (diagonal forward-right), idles FR and
RR instead. Run **both** — see §5.3.

---

## 12. Summary of results

```
k    = (wheelbase_mm + track_width_mm) / 2        front yaw lever
m    = (wheelbase_mm - track_width_mm) / 2        rear  yaw lever

IK:  ω_FL = ( vx - vy - k*w ) / wheel_radius_mm
     ω_FR = ( vx + vy + k*w ) / wheel_radius_mm
     ω_RL = ( vx - vy + m*w ) / wheel_radius_mm
     ω_RR = ( vx + vy - m*w ) / wheel_radius_mm

     f_i  = ω_i * 3200 / (2*π)

FK:  Δ_F = ω_FL - ω_FR        Δ_R = ω_RL - ω_RR

     vx = (wheel_radius_mm / 4) * ( ω_FL + ω_FR + ω_RL + ω_RR )

     vy = (wheel_radius_mm / (4*wheelbase_mm))
                * ( (track_width_mm - wheelbase_mm) * Δ_F
                  - (track_width_mm + wheelbase_mm) * Δ_R )

     w  = (wheel_radius_mm / (2*wheelbase_mm)) * ( -Δ_F + Δ_R )

Null space (unchanged): ( +ω_FL + ω_FR - ω_RL - ω_RR ) = 0
```

No numeric geometry constant appears anywhere above. Changing wheel size or
frame dimensions is a `params.json` edit.

---

## 13. What the layout change moved — a reviewer's checklist

For anyone holding a printout of the previous (X-drive) edition, or reviewing
the port.

### Changed

| | Was (X-drive) | Now (parallel rollers) |
|---|---|---|
| Shared roller tilt | FL+RR, and FR+RL | **FL+RL, and FR+RR** |
| `δ` assignment | FL −1, FR +1, RL **+1**, RR **−1** | FL −1, FR +1, RL **−1**, RR **+1** |
| Yaw lever arms | `±k` on all four | **`±k` front, `±m` rear** — 64.7:1 |
| Rear-wheel IK rows | `vx + vy ∓ k*w` | **`vx − vy ± m*w`** |
| Strafe pattern | diagonals `(−,+,+,−)` | **sides `(−,+,−,+)`** |
| Bench idle test | `vx = vy` idles FL **and RR** | **idles the whole LEFT SIDE** |
| `MᵀM` | diagonal | **not diagonal** — `c_vy · c_w = 2W` |
| FK yaw scale | `r / (2(L+W))` | **`r / (2L)`** — track width drops out |
| FK structure | yaw ← side pattern, strafe ← diagonal pattern | **yaw ← Δ_F − Δ_R, strafe ← weighted Δ_F + Δ_R** |
| Odometry error gain | baseline | **1.44× on `vy`, 2.03× on `w`** |

### Unchanged

| | |
|---|---|
| Body frame, sign conventions, wheel positions | §2, §3 |
| Rigid-body contact-patch velocity (4.1) | §4 |
| The general per-wheel constraint (5.3) | §5 — only the four `δ` differ |
| Front-wheel IK rows | `vx ∓ vy ∓ k*w` exactly as before |
| Forward motion, and the `vx` FK row | all four wheels equal; `(r/4)·Σω` |
| Step-rate conversion, `STEPS_PER_RAD` | §7 |
| **Null space `(+1,+1,−1,−1)`** | §9.2 — and hence the slip metric |
| Peak wheel rate per unit motion | §9.3 — same top speed, strafe and yaw rate |
| Holonomy | §8.2 — rank 3 for any non-zero wheelbase |
| Clamp, deadband and pipeline ordering rules | §10 |

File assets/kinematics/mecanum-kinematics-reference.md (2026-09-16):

# Mecanum Kinematics — Quick Reference

**Project:** OMNIS · 4-wheel holonomic mecanum platform
**Layout:** **lateral parallel rollers** — left pair alike, right pair mirrored
**Scope:** Notation, equations, sign conventions, RC channel mapping, and
verified numbers. No derivation — see
[`mecanum-kinematics-derivation.md`](mecanum-kinematics-derivation.md) for that.

> **Not a textbook X-drive.** Both left wheels carry the same roller tilt and
> both right wheels the mirror, so the standard mecanum matrix does not describe
> this robot. If you arrived here with the usual `±(L+W)/2`-on-all-four formula
> in mind, read §2 carefully — the rear rows differ.

---

## 1. Notation

### Body-frame quantities

Right-handed frame, ROS REP-103 convention.

| Symbol | Quantity | Positive direction | Unit |
|---|---|---|---|
| `vx` | longitudinal velocity | **forward** | mm/s |
| `vy` | lateral velocity (strafe) | **left** | mm/s |
| `w` | yaw rate | **counter-clockwise** from above | rad/s |
| `ω_i` | wheel angular velocity | sense that drives robot **forward** | rad/s |
| `f_i` | step-pulse rate | sign follows `ω_i` | microsteps/s |

**Unit rule:** geometry is in mm, so `vx`/`vy` must be in **mm/s**. Yaw is in
**rad/s**. Mixing in m/s breaks the yaw term by 1000× while forward motion still
looks correct — normalise once at the RC input layer.

### Geometry parameters — from `params.json`

| Name | Meaning | OMNIS value |
|---|---|---|
| `wheel_radius_mm` | wheel radius | 30 |
| `wheelbase_mm` | front-to-back wheel-centre distance | 223 |
| `track_width_mm` | left-to-right wheel-centre distance | 230 |

### Fixed drivetrain constants — hard-wired, not parameters

| Name | Value | Source |
|---|---|---|
| `MOTOR_FULL_STEPS_PER_REV` | 200 | 1.8°/step NEMA17 |
| `A4988_MICROSTEPS` | 16 | MS1/MS2/MS3 tied HIGH |
| `MICROSTEPS_PER_REV` | 3200 | 200 × 16 |
| `STEPS_PER_RAD` | 509.295818 | 3200 / (2π) |

### Derived quantities — **two** yaw lever arms, not one

```
k = (wheelbase_mm + track_width_mm) / 2      [mm]   FRONT pair yaw lever
m = (wheelbase_mm - track_width_mm) / 2      [mm]   REAR  pair yaw lever
```

For OMNIS: `k = 226.5 mm`, `m = -3.5 mm`, `k/r = 7.55`, `|k/m| = 64.7`.

The single `k` of the X-drive no longer exists. The front axle carries **98.5%**
of the yaw authority; the rear axle's lever is small, and its **sign flips** if
the frame is ever made longer than it is wide (`m = 0` at `L = W`).

Identities used throughout: `k + m = L`, `k - m = W`.

---

## 2. Inverse kinematics

### Mixing matrix

```
                  ┌                       ┐
 ┌      ┐         │   1     -1     -k     │   ┌      ┐
 │ ω_FL │         │                       │   │  vx  │
 │ ω_FR │    1    │   1     +1     +k     │   │  vy  │
 │ ω_RL │  = ───  │                       │ · │   w  │
 │ ω_RR │    r    │   1     -1     +m     │   └      ┘
 └      ┘         │                       │
                  │   1     +1     -m     │
                  └                       ┘
```

### Written out

```
ω_FL = ( vx - vy - k*w ) / wheel_radius_mm
ω_FR = ( vx + vy + k*w ) / wheel_radius_mm
ω_RL = ( vx - vy + m*w ) / wheel_radius_mm
ω_RR = ( vx + vy - m*w ) / wheel_radius_mm
```

The **front two rows are identical to the X-drive's**; both rear rows differ, in
the `vy` sign and in the lever. That is a fast way to spot a half-finished port.

### To step-pulse rate

```
f_i = ω_i * STEPS_PER_RAD                     STEPS_PER_RAD = 3200/(2π)
```

### Fully combined

```
f_FL = ( vx - vy - k*w ) * 509.295818 / wheel_radius_mm
f_FR = ( vx + vy + k*w ) * 509.295818 / wheel_radius_mm
f_RL = ( vx - vy + m*w ) * 509.295818 / wheel_radius_mm
f_RR = ( vx + vy - m*w ) * 509.295818 / wheel_radius_mm
```

`sign(f_i)` → A4988 `DIR` pin. `|f_i|` → `STEP` pulse rate.

---

## 3. Forward kinematics — commanded-velocity estimate

Open-loop, no encoders: this is what the wheels were **asked** to do, not what
they did.

In terms of the two **axle differentials** — where this form is cleanest:

```
Δ_F = ω_FL - ω_FR                Δ_R = ω_RL - ω_RR

vx = (wheel_radius_mm / 4) * ( ω_FL + ω_FR + ω_RL + ω_RR )

vy = (wheel_radius_mm / (4*wheelbase_mm))
            * ( (track_width_mm - wheelbase_mm) * Δ_F
              - (track_width_mm + wheelbase_mm) * Δ_R )

w  = (wheel_radius_mm / (2*wheelbase_mm)) * ( -Δ_F + Δ_R )
```

> **Yaw is the difference of the two axle differentials; strafe is their
> weighted sum.** The X-drive had it the other way round — yaw from the side
> pattern, strafe from the diagonal. Getting these two backwards is the classic
> port error, and it is silent: forward motion still works and only strafe and
> yaw come out swapped.

Note `track_width_mm` does **not** appear in the `w` row. Yaw resolution is set
by the wheelbase alone, because `det(MᵀM) = 4L²`.

From step rates: `ω_i = f_i / 509.295818`

### Slip / health check

This wheel-speed combination — the **front pair opposing the rear pair** —
produces **no body motion** and should always be zero for a correctly-formed
command:

```
null = ( +ω_FL + ω_FR - ω_RL - ω_RR )
```

**Unchanged from the X-drive.** It annihilates all three motion columns for
either roller handedness and any geometry — the one result the layout change
left completely alone.

Non-zero means something corrupted the command downstream of the IK — a
per-wheel clamp, a saturated axis, or a wrong invert flag. The drivetrain is
fighting itself.

### Precision cost

The `vy` and `w` columns are no longer orthogonal — they meet at **44.1°**
(`cos θ = W/√(L²+W²)`). Reachability is unaffected, but the least-squares
estimate amplifies per-wheel error more: **1.44× on `vy`, 2.03× on `w`** against
the X-drive, for the same steppers. Dead reckoning drifts correspondingly
faster. `vx` is unaffected.

---

## 4. Sign convention per wheel

### Which physical corner is which — as-built

Confirmed against the assembled board, 2026-09-05. **Front is the OLED / button
end.** Everything below is stated in these labels, so getting this wrong inverts
the meaning of the whole table.

```
                     +X  FRONT
                       ^
                       |
   ┌───────────────────┼───────────────────┐
   │  FL  [motor] /    |    \ [motor]  FR  │
   │  IMU_A 0x68       |                   │
   │              OLED + buttons           │
+Y │- - - - - - - - - -+- - - - - - - - - -│ -Y
LEFT                   |                  RIGHT
   │                 ESP32-S3              │
   │                   |       IMU_B 0x69  │
   │  RL  [motor] /    |    \ [motor]  RR  │
   └───────────────────┼───────────────────┘
                      REAR
```

Right-handed, +Z out of the page. Identical frame to
[`../control/omnis_imu_mounting.h`](../control/omnis_imu_mounting.h), which
carries the same diagram for the estimation side.

The `/` and `\` marks are the **roller axes** as seen from above: both left
wheels alike, both right wheels the mirror.

| Wheel | Roller `δ` | Tilt | `vx` | `vy` (left+) | `w` (CCW+) |
|---|---|---|---|---|---|
| **FL** | −1 | `/` | +1 | **−1** | **−k** |
| **FR** | +1 | `\` | +1 | **+1** | **+k** |
| **RL** | −1 | `/` | +1 | **−1** | **+m** |
| **RR** | +1 | `\` | +1 | **+1** | **−m** |

**Roller handedness pairing:**
- **FL + RL** (the left side) → `δ = -1`, axis on the forward-right diagonal,
  drawn `/`. Negative on `vy`.
- **FR + RR** (the right side) → `δ = +1`, axis on the forward-left diagonal,
  drawn `\`. Positive on `vy`.

In firmware these four signs are `MECANUM_DELTA_FL` … `MECANUM_DELTA_RR` in
[`mecanum_kinematics.h`](mecanum_kinematics.h) — the **only** place the layout
is stated. The `vy` signs and both lever arms are computed from them.

If the physical wheels are mirrored from this, negate **all four `δ` together**
and rebuild. The `vy` **and** `w` columns then both flip; they are not
independent, so do not flip one by hand, and never "fix" a wrong strafe with a
`DIR` invert flag.

### Motion pattern cross-check

| Motion | Input | FL | FR | RL | RR | Split |
|---|---|---|---|---|---|---|
| Forward | `vx > 0` | + | + | + | + | none — all same |
| Backward | `vx < 0` | − | − | − | − | none — all same |
| Strafe **left** | `vy > 0` | **−** | **+** | **−** | **+** | **sides**, equal magnitude |
| Strafe right | `vy < 0` | + | − | + | − | **sides**, equal magnitude |
| Rotate **CCW** | `w > 0` | **−** | **+** | **−** | **+** | **sides**, front 64.7× rear |
| Rotate CW | `w < 0` | + | − | + | − | **sides**, front 64.7× rear |
| Diagonal fwd-left | `vx = vy > 0` | **0** | + | **0** | + | **left side idles** |
| Diagonal fwd-right | `vx = -vy > 0` | + | **0** | + | **0** | **right side idles** |

Strafe and rotation now share the **same sign pattern** and are told apart only
by the front:rear *magnitude ratio* — 1:1 for strafe, 64.7:1 for yaw. Under an
X-drive they had visibly different patterns; they no longer do.

**Bench test — run BOTH directions.** Command `vx = vy` (diagonal forward-left):
both **left** wheels must be completely stationary. Then command `vx = -vy`:
both **right** wheels must be stationary instead.

- Correct side idles both times → handedness is right.
- The *other* side idles → handedness is mirrored; negate all four `δ`.
- A *diagonal* pair idles → the wheels are not in the parallel layout at all.
- Anything else → a `DIR` invert flag is wrong. Fix forward motion first.

---

## 5. RC channel mapping

Unaffected by the layout change. Fixed input scheme: throttle → `vx`, yaw stick
→ `w`, pitch + roll → `vy` and secondary `vx`.

```
vx = throttle_norm * VX_MAX_MMPS  +  pitch_norm * VX_SECONDARY_MMPS
vy = roll_norm     * VY_MAX_MMPS
w  = yaw_norm      * W_MAX_RADPS
```

Each `*_norm` is in the range [−1, +1].

| Channel | Drives | Positive stick | Scale constant | Unit |
|---|---|---|---|---|
| Throttle | `vx` (primary) | forward | `VX_MAX_MMPS` | mm/s |
| Pitch | `vx` (secondary) | forward | `VX_SECONDARY_MMPS` | mm/s |
| Roll | `vy` | **left** | `VY_MAX_MMPS` | mm/s |
| Yaw | `w` | **left / CCW** | `W_MAX_RADPS` | rad/s |

**Stick polarity:** yaw stick left → `w` positive (CCW). Roll stick left → `vy`
positive. If your transmitter is right-positive on either axis, negate **at this
mapping layer only**. Never negate inside the kinematics.

**Combined `vx`:** throttle and pitch both feed `vx` additively, so the sum can
exceed `VX_MAX_MMPS`. Clamp the combined `vx` before it reaches the IK, or rely
on the common-factor wheel clamp in §6 — but not both, or the response becomes
non-linear near full stick.

---

## 6. Implementation checklist

| Rule | Why |
|---|---|
| State the roller layout **only** in `MECANUM_DELTA_*`, and negate all four together | Both `vy` signs and both lever arms are derived from them; changing one without the others is not a valid configuration |
| Clamp with a **common scale factor** on all four wheels | Per-wheel clipping warps the motion vector — a strafe becomes an arc |
| Clamp **before** computing FK | Feeding pre-clamp values into dead reckoning is the classic open-loop drift bug: the estimator believes a velocity the hardware never produced |
| Handle motor mirroring with a per-wheel `dir_invert` flag at the GPIO layer | Flipping a matrix sign to fix a backwards motor breaks the FK round-trip and every other motion using that wheel |
| Deadband small commands — below ≈20 steps/s, hold stopped | A4988 needs `DIR` stable ≥200 ns before a `STEP` edge; a wheel dithering across zero will chatter |
| Expect the **rear pair to deadband during slow yaw** | Their lever is 1.5% of the front's, so below ≈0.34 rad/s they sit below the deadband while the front pair drives. Correct, not a dead motor |
| Keep geometry in `params.json`, passed as arguments | Changing wheel size or frame dimensions must not require touching the function body |
| Unit-test the IK→FK round trip **on each axis separately** | A rank-deficient layout fails only one axis; a combined test can mask it |

---

## 7. Verified numbers — OMNIS build

`wheel_radius_mm = 30`, `wheelbase_mm = 223`, `track_width_mm = 230`
→ `k = 226.5 mm`, `m = -3.5 mm`, `STEPS_PER_RAD = 509.295818`, `k/r = 7.55`

These are the values `test/test_kinematics.c` and the firmware's boot self-check
both assert. If a refactor disagrees with this table, this table is right.

### Case A — pure forward, `vx = 200 mm/s`

| Wheel | ω (rad/s) | f (µsteps/s) |
|---|---|---|
| FL | +6.66667 | +3395.305 |
| FR | +6.66667 | +3395.305 |
| RL | +6.66667 | +3395.305 |
| RR | +6.66667 | +3395.305 |

Unchanged from the X-drive — forward motion never involved handedness.

### Case B — pure strafe left, `vy = 200 mm/s`

| Wheel | ω (rad/s) | f (µsteps/s) |
|---|---|---|
| FL | −6.66667 | −3395.305 |
| FR | +6.66667 | +3395.305 |
| RL | −6.66667 | −3395.305 |
| RR | +6.66667 | +3395.305 |

Left side back, right side forward, all four equal magnitude. Same wheel speed
as forward for the same body speed. It feels weaker because only the roller-axis
force component reaches the floor — expected, not an error.

### Case C — pure rotation CCW, `w = 1.0 rad/s`

| Wheel | ω (rad/s) | f (µsteps/s) |
|---|---|---|
| FL | −7.55000 | −3845.183 |
| FR | +7.55000 | +3845.183 |
| RL | **−0.11667** | **−59.418** |
| RR | **+0.11667** | **+59.418** |

**The signature case.** The rear pair crawls at 1.5% of the front pair. If all
four come out at 3845, the build is still running X-drive kinematics.

Below about **0.34 rad/s** of commanded yaw the rear pair falls under a 20
steps/s deadband and is held stopped while the front pair drives.

### Case D — combined, `vx = 200`, `vy = 100`, `w = 0.5`

`k*w = +113.25 mm/s`, `m*w = -1.75 mm/s`

| Wheel | Arithmetic | ω (rad/s) | f (µsteps/s) | DIR |
|---|---|---|---|---|
| FL | (200 − 100 − 113.25)/30 | −0.441667 | **−224.939** | reverse |
| FR | (200 + 100 + 113.25)/30 | +13.775000 | **+7015.550** | forward |
| RL | (200 − 100 − 1.75)/30 | +3.275000 | **+1667.944** | forward |
| RR | (200 + 100 + 1.75)/30 | +10.058333 | **+5122.667** | forward |

FK round-trip → `(200.0, 100.0, 0.5)` ✓ · null-space check → `0.000` ✓

**Practical limits visible in Case D:**
- FR at 7016 µsteps/s = 2.19 rev/s ≈ **131 RPM**. The A4988 handles that pulse
  rate fine, but a NEMA17 on 12 V is well off its torque curve there. Case D is
  near the practical ceiling of this build.
- FL at −225 µsteps/s sits close to zero and will chatter across the direction
  reversal — this is what the deadband in §6 is for.
- The rear pair's spread (1668…5123) is far narrower than the front pair's
  (−225…7016), because only the front carries the yaw term meaningfully. **The
  front wheels reach the clamp first whenever yaw is commanded.**

### Case E — the handedness bench test

`vx = vy = 200` (diagonal forward-left) → FL and RL exactly **0**, FR and RR at
**+6790.611**.
`vx = 200, vy = -200` (forward-right) → FR and RR exactly **0**, FL and RL at
**+6790.611**.

Run both. See §4.

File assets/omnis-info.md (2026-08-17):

# OMNIS — Project Info File

**Name:** OMNIS — **O**mnidirectional **M**obility and **N**on-holonomic **I**nertial **S**tabilization

---

## 1. Project Goal

A four-wheel car, each wheel driven by its own stepper motor, built as a personal embedded-systems portfolio piece. Two headline capabilities:

1. **Holonomic drive** — Magnum (angled-roller/Mecanum-style) wheels give full directional control: strafe, rotate in place, move diagonally, without needing to turn first.
2. **Self-balancing mode** — the car can also tip up and balance/drive on two wheels, Segway-style, in addition to normal 4-wheel driving.

**Balance-mode wheel behavior (confirmed):** all four steppers stay powered and active during 2-wheel balance mode — none are mechanically or electrically disengaged. This is deliberate: the platform needs to be able to balance on *either* side, so if it's flipped mid-run the "new" pair of wheels needs to be immediately drivable without a mode-switch delay. Firmware/control implication: the balance controller needs to know (or detect) which side is currently down and re-map which two wheels are "active" for balance thrust vs. which two are along for the ride, rather than assuming a fixed pair.

The name is deliberately left open-ended (not tied to "car" or "stepper" specifically) since this platform may extend into further omnidirectional-wheel work down the line.

**Software philosophy:** written from scratch by the builder, with light AI assistance only — not vibe-coded. Deliberately chosen stack:

- Bare-metal-style programming on the ESP32-S3 (not just calling high-level Arduino libraries)
- A custom RTOS layer, built on top of FreeRTOS (which ships inside ESP-IDF) — see `vscode-setup.md` §8 for the learning path
- Custom peripheral drivers rather than pulling in ready-made libraries wherever reasonably feasible
- An EKF (Extended Kalman Filter) fusing the two IMUs for attitude/balance estimation

---

## 2. Components

| Module | Part | Notes |
|---|---|---|
| Wheel motors (×4) | Nidec Servo Corporation **KV4239-T3B004** (OEM cross-ref FK2-7586) | 2-phase hybrid stepper, NEMA17-class (42mm), KV42 series |
| Stepper drivers (×4) | **A4988** | One per motor, U2–U5. RST#/SLP# tied to VCC — resolved, no longer floating |
| Wheels (×4) | **Magnum wheels** (omnidirectional, angled-roller/Mecanum-style) | Angled rollers around the rim enable true sideways/diagonal movement for holonomic drive |
| MCU module | **ESP32-S3-WROOM-1-N16R8** (16MB flash / 8MB Octal PSRAM) on EdgeHax S3 Pro dev board | N16R8 confirmed by builder. PSRAM conflict resolved — FR_STEP/FR_DIR/RR_DIR/B_DOWN moved off GPIO35–38 onto GPIO39–42 (§3a/§3b), so module PSRAM variant (Octal vs Quad) no longer matters for this design. |
| Dev board | **EdgeHax S3 Pro** | Schematic symbol: `ESP32-S3PRO-DEVKIT-edgehax` |
| IMUs (×2) | **MPU6050** (U6, U7) | Mounted at diagonally opposite corners for redundant/fused attitude sensing. AD0 address collision resolved: U6 = 0x68, U7 = 0x69 |
| Display | **SSD1306**-based 128×64 I2C OLED (schematic symbol `DISPLAY-OLED-128X64-I2C`, designator G$1) | Controller part confirmed by builder — schematic still uses the generic OLED symbol, which is fine since the symbol doesn't need to change; drive it as SSD1306 |
| RC link | **RadioMaster Pocket** TX + **ExpressLRS Nano Rx** receiver (U10) | CRSF over UART — see §3c for the TX/RX crossover |
| Buzzer | **Buzzer Module** (U9, 3-pin: VCC / IO / GND) | Has its own driver IC onboard (not a bare piezo) — IO pin is a logic-level control signal |
| Buttons | 6× tactile, 4-pin (K4-6×6_TH) — Up / Down / Left / Right / Select / Special-function (B_SF) | Special-function opens an on-screen config/setup menu on the display (EdgeTX-menu-style, §14). Wired **active-HIGH** |
| Battery | 3S LiPo (schematic power-in header labeled "12V", nominal for 3S) | Powers whole system via 2-pin header H5. **No dedicated power switch planned** — board is live whenever the battery is connected; power-off = unplug. Voltage sensed via a divider on GPIO6 — see §3g |
| Regulator | **L7805CV** (U8) | INPUT ← battery rail, OUTPUT → regulated 5V logic rail (net "VCC" throughout the schematic) |
| Capacitors | 9× 150µF electrolytic (U11–U19) | One per: I2C/OLED rail, each MPU6050 (×2), each A4988 logic rail (×4), ESP32 5V input, main battery input. No voltage rating specified in the schematic — pick per rail (25V+ for the 12V/battery side, lower is fine for the 5V logic side) |

## 3. ESP32-S3PRO GPIO Pinout — verified against schematic rev 1.0 (as revised 2026-08-16)

### 3a. Connected / used pins

| GPIO | Net label | Connects to | Notes |
|---|---|---|---|
| 1 | COM_ENA | EN# on **all four** A4988 drivers (shared) | Single enable line for all steppers |
| 2 | B_RIGHT | Right button | Active-HIGH |
| 3 | B_SF | Special-function button | Active-HIGH. |
| 4 | FL_STEP | Front-Left A4988 STEP | |
| 5 | FL_DIR | Front-Left A4988 DIR | |
| 6 | BATT_SENSE | Battery voltage divider (3S LiPo → 0–3.3V) | ADC1_5 — see §3g for divider values and cutoff thresholds |
| 8 | SDA | I2C bus (shared: OLED + both MPU6050s) | |
| 9 | SCL | I2C bus (shared) | Not part of the microSD wiring — confirmed against the board's pinout diagram; the SD socket only uses GPIO10–13 (§9b) |
| 10 | SD_CS | microSD slot, `FSPICS0` | SD card SPI chip-select — confirmed from EdgeHax pinout diagram (§9b) |
| 11 | SD_MOSI | microSD slot, `FSPID` | SD card SPI data-out (host→card) — confirmed from EdgeHax pinout diagram (§9b) |
| 12 | SD_CLK | microSD slot, `FSPICLK` | SD card SPI clock — confirmed from EdgeHax pinout diagram (§9b) |
| 13 | SD_MISO | microSD slot, `FSPIQ` | SD card SPI data-in (card→host) — confirmed from EdgeHax pinout diagram (§9b) |
| 14 | BUZZ | Buzzer Module IO | Not part of the microSD wiring — confirmed against the board's pinout diagram; the SD socket only uses GPIO10–13 (§9b) |
| 15 | RL_STEP | Rear-Left A4988 STEP | |
| 16 | RL_DIR | Rear-Left A4988 DIR | |
| 17 | (net "RX") | ExLRS Rx **Tx** pin | ESP32 role = UART **TX** (sends to receiver) — see §3c |
| 18 | (net "TX") | ExLRS Rx **Rx** pin | ESP32 role = UART **RX** (receives CRSF from receiver) — see §3c |
| 21 | RR_STEP | Rear-Right A4988 STEP | |
| 39 (MTCK) | B_DOWN | Down button | Active-HIGH. Moved here from GPIO35 on 2026-08-16 to clear the PSRAM-conflict pins (§3b) |
| 40 (MTDO) | FR_DIR | Front-Right A4988 DIR | |
| 41 (MTDI) | FR_STEP | Front-Right A4988 STEP | |
| 42 (MTMS) | RR_DIR | Rear-Right A4988 DIR | |
| 45 | B_SELECT | Select button | Active-HIGH. |
| 47 | B_LEFT | Left button | Active-HIGH |
| 48 | B_UP | Up button | Active-HIGH |

### 3b. Unconnected / spare pins (per revised schematic)

GPIO 0, 7, 35, 36, 37, 38, 43 (U0TX), 44 (U0RX), 46, 19 (USB D−), 20 (USB D+). Also both 3V3 pins and RST are unconnected/not wired to anything in this schematic. Two of the board's GND pins on the right side and one on the top-right are likewise unwired stubs (the board's other GND pins do the actual return-current work).

GPIO 6 — previously listed here — is now the battery-voltage sense line (§3g). GPIO 10, 11, 12, 13 — also previously listed here — are now claimed by the onboard microSD slot (SPI CS/MOSI/CLK/MISO, §9b); both moved to §3a.

GPIO35–38 are now the spare pins (freed up by the move to 39–42, detailed above), a reversal from the original layout where 35–38 were used and 39–42 were spare.

Note GPIO43/44 (the chip's default UART0 TX/RX, normally used for USB-serial flashing/monitor) are spare here — confirms ExLRS is on a separate UART (17/18), not sharing the flashing port.

### 3c. ExpressLRS UART — net names are from the receiver's perspective

The schematic net called **"RX"** connects to the ExLRS Rx module's own **Rx** input pin, and the net called **"TX"** connects to its **Tx** output pin. Since the receiver's Tx must feed the ESP32's RX, and the receiver's Rx must be fed by the ESP32's TX, the roles are the **reverse** of the label when you configure the ESP32's UART:

- **GPIO17** (on the "RX" net) → configure as ESP32 UART **TX** in firmware
- **GPIO18** (on the "TX" net) → configure as ESP32 UART **RX** in firmware

This is a common gotcha — worth a code comment when you set up the UART driver.

### 3d. Buttons are active-HIGH

All six buttons wire one leg to VCC and the other leg out to the GPIO net. Pressed = pin pulled to VCC (HIGH). Idle = pin floats unless you add a pull-down. **You'll need internal pull-downs enabled (or external pull-down resistors)** on all six button GPIOs — the opposite of the "active-low with internal pull-ups" assumption in earlier notes. **Still open** — internal vs. external pull-downs not yet decided (see §5).

### 3e. Strapping pins reused as button/driver inputs

GPIO3 (B_SF) and GPIO45 (B_SELECT) are two of the ESP32-S3's four strapping pins (sampled only at reset/boot). Since these buttons idle LOW (with a pull-down) and are only pulled HIGH when physically pressed, this should be safe in normal use — just avoid holding Special-Function or Select down while power-cycling the board, since that could alter boot behavior (GPIO45 in particular affects VDD_SPI voltage selection).

Related consideration: GPIO39–42 are the chip's default JTAG pins (MTCK/MTDO/MTDI/MTMS), and whether they behave as plain GPIO depends on the JTAG signal-source strap, which is GPIO3 (B_SF) itself. Since B_SF idles low, JTAG stays on its USB-JTAG default and 39–42 behave as ordinary GPIO in normal operation — the only failure mode is holding B_SF down through a power-cycle, the same caution as above, now extended to four load-bearing driver pins instead of just spares.

### 3f. A4988 driver wiring (all four identical: U2–U5)

- **EN#** ← COM_ENA (shared)
- **MS1/MS2/MS3/RST#/SLP#** — all five bridged together and tied to VCC (5V logic), which fixes microstepping at **1/16** (MS1=MS2=MS3=HIGH per the A4988 truth table) — 200 full steps/rev × 16 = 3200 microsteps/rev. Referenced by §10's kinematics prompt.
- **STEP/DIR** → per-wheel GPIOs (§3a)
- **VMOT/GND** → battery rail / GND (motor power)
- **VDD/GND** → 5V logic rail / GND (driver logic power), each with its own 150µF decoupling cap
- **2B/2A/1A/1B** (motor coil outputs) → 4-pin header per driver (H1–H4) going to the physical motor connector
- **Current-limit (Vref) trim pot** — not yet set. Each A4988 has an onboard pot setting `Imax = Vref / (8 × Rsense)`; get this wrong and you either starve the motors of torque or overheat a driver/motor on first power-up. Set per the KV4239-T3B004's rated current before ever spinning a wheel — see §13c for why generous margin here also matters for balance-mode reliability.

### 3g. Battery voltage sense (GPIO6)

3S LiPo pack voltage sensed via a resistive divider into GPIO6 (ADC1_5 — deliberately an ADC1 pin rather than ADC2, since ADC2 is the one that gets unreliable while Wi-Fi is active on this chip family; this sidesteps that for free).

Divider: **R_top = 120kΩ** (battery+ side) to **R_bottom = 33kΩ** (GPIO6 to GND), ratio ≈ 0.216. At a full 3S charge (12.6V) that's ~2.72V at the pin — safely under the 3.3V ADC ceiling with margin for an overvoltage fault; at a near-empty pack (9V) it's ~1.94V, still well inside the ADC's usable range. Add a 100nF cap across R_bottom to filter switching noise from the nearby steppers.

Use ESP-IDF's ADC calibration API (`adc_cali_create_scheme_curve_fitting` on ESP32-S3) rather than raw ADC counts — the raw-to-voltage mapping is non-linear enough on this chip to matter for a threshold-triggered cutoff.

Firmware thresholds (standard 3S LiPo guidance, stored in `params.json` → `battery`, §9f): warn at 3.5V/cell (10.5V pack, buzzer chirp), hard cutoff at 3.3V/cell (9.9V pack, force COM_ENA disable regardless of drive mode) — over-discharging a LiPo is a safety issue, not just a performance one.

---

## 5. Open Items / Not Yet Finalized

- **RC channel/switch semantics (§7d)** — "emergency skill switch" read as **emergency kill switch** (assumed transcription); heading-hold momentary button's hold-vs-toggle behavior; and what the IMU trim potentiometer trims (static balance-setpoint bias vs. live gain) are all still undefined. Pick these before writing the input-handling state machine, not while debugging it.

## 6. Related Files

- `vscode-setup.md` — fresh-install VS Code + ESP-IDF + FreeRTOS environment setup for this project

---

## 7. RC Control Scheme — RadioMaster Pocket / ExpressLRS
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

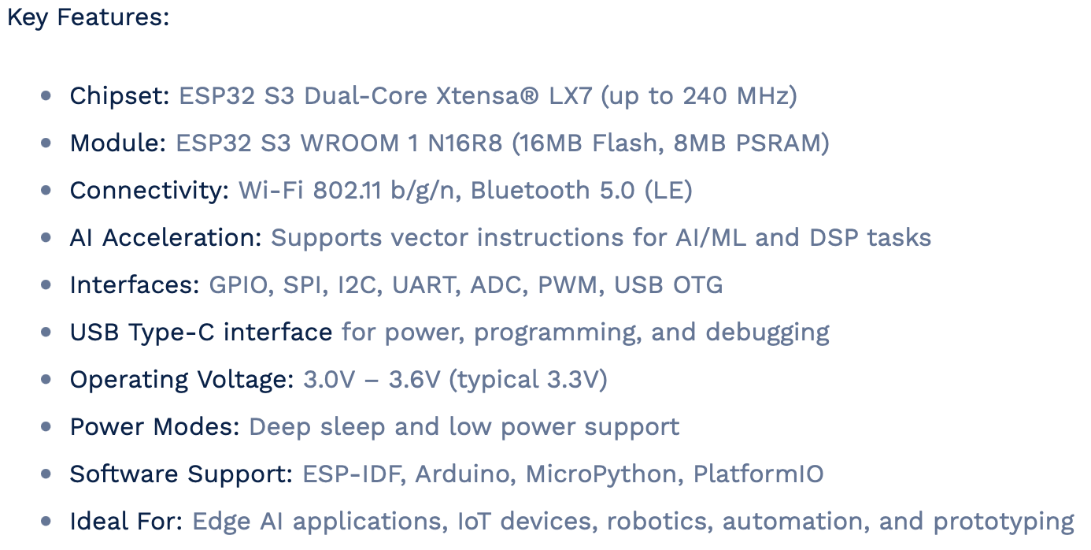
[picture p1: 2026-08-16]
assets/documentation/s3-pro-docs/Key Features.png

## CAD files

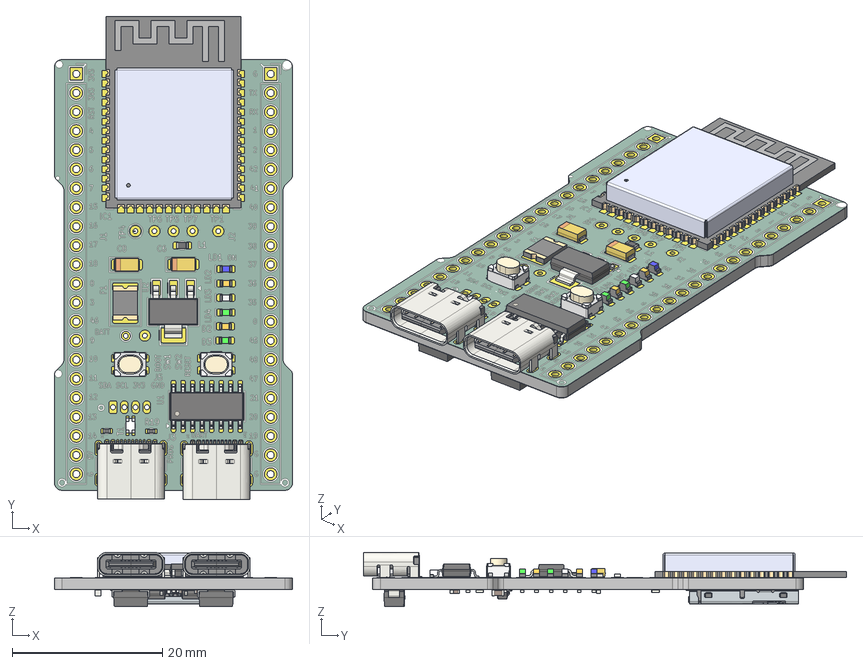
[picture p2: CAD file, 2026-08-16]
assets/documentation/s3-pro-docs/CAD Model/EDGEHAX-S3-PRO-STEP-FILE-3D.step
31.8 x 64.4 x 7.21 mm
LED_0603_1608Metric_Blue
Choke_100MHz_USB_RFCMF1220100M4T
R_0402_1005Metric x 20
USB_C_Receptacle_GCT_USB4105-xx-A_16P_TopMnt_Horizontal x 2
SOT-223
PTS815SJM250SMTRLFS_PART3 x 10
PTS815SJM250SMTRLFS_PART2 x 4
PTS815SJM250SMTRLFS_PART1 x 2
LED_0603_1608Metric_Orange x 2
Fuse_1812_4532Metric
SOIC-16_3.9x9.9mm_P1.27mm
CP_EIA-3216-12_Kemet-S x 2
LED_0603_1608Metric_Green x 2
R_0603_1608Metric
ESP32-S3-WROOM-1-N8R2--3DModel-STEP-56544
LED_0603_1608Metric_White
C_0603_1608Metric x 2
SOT-23 x 2
D_SMA x 2
CSD03S010R x 14
C_0402_1005Metric x 5
S3-PRO-3D_copper
S3-PRO-3D_silkscreen x 2
S3-PRO-3D_soldermask x 2
S3-PRO-3D_PCB

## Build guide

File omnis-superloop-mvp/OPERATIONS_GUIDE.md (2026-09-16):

# OMNIS Superloop MVP — Developer & Operations Guide

Everything needed to build the firmware, understand how it runs, find the file
that owns a behaviour, and change the numbers that usually need changing.

**Target:** ESP32-S3 (EdgeHax S3 Pro / DevKitC-1 class), board **Rev 2.0** ·
ESP-IDF **v6.0.2** · no FreeRTOS primitives in OMNIS-authored code.

| Companion document | Read it for |
|---|---|
| **[TESTING.md](TESTING.md)** | Bench bring-up, stage by stage. **Read §0 before applying 12 V.** |
| [README.md](README.md) | One-page overview and current status |
| [BUILD-LOG.md](BUILD-LOG.md) | Scope, the settled decisions, the stage-by-stage commit table, and the full construction history with every bug found |
| [../assets/documentation/omnis-info.md](../assets/documentation/omnis-info.md) | The project info file — the full spec, with per-section notes on what this build does |
| [../assets/kinematics/](../assets/kinematics/) | The drivetrain maths, derived from first principles |
| [../assets/control/](../assets/control/) | EKF, fusion and PID derivations |

> ### Safety, once, at the top
> Board Rev 2.0 **hardwires the A4988 `EN#` line**. The motors are energised
> whenever 12 V is present — before the firmware has run, and while it is
> halted in a fault. Nothing in software can de-energise them; only unplugging
> can. **Set the four A4988 `Vref` current limits before the first power-up**
> (TESTING.md §0), and keep the wheels off the ground for everything up to and
> including Stage 5.

---

## 1. Build and flash

### 1.1 One-time environment

ESP-IDF v6.0.2 is installed natively. Activate it with the **tools activation
script**, not `export.sh`:

```bash
. ~/.espressif/tools/activate_idf_v6.0.2.sh
```

> `export.sh` looks for a Python 3.11 virtualenv while this install runs on
> 3.14, so it fails where the activation script works. This is the reason the
> command looks unusual; it is not a typo.

Confirm the toolchain is live:

```bash
idf.py --version && xtensa-esp32s3-elf-gcc --version | head -1
```

### 1.2 Build

The project is a sub-directory of the repository, so build it with `-C` from
the repository root — or `cd` into it first; both work.

```bash
cd /Volumes/Projects/OMNIS && idf.py -C omnis-superloop-mvp build
```

A clean build ends with the partition report. Expect roughly:

```
omnis_superloop_mvp.bin binary size 0x3bda0 bytes.
Smallest app partition is 0x100000 bytes. 0xc4260 bytes (77%) free.
```

The build must be **warning-free**. Warnings are not tolerated here because the
whole safety argument rests on the compiler having nothing to say.

### 1.3 Flash and monitor

Find the port first — the ESP32-S3's native USB enumerates as `usbmodem`:

```bash
ls /dev/cu.usbmodem* /dev/cu.SLAB* /dev/cu.wchusb* 2>/dev/null
```

```bash
cd /Volumes/Projects/OMNIS && idf.py -C omnis-superloop-mvp -p /dev/cu.usbmodem101 flash monitor
```

Leave the monitor attached: the boot sequence prints the self-checks that tell
you whether the board is healthy, and the once-a-second telemetry line is the
main diagnostic instrument for everything in TESTING.md.

Exit the monitor with **Ctrl-]**.

If flashing fails to connect, hold **BOOT**, tap **RESET**, release **BOOT**,
and retry.

### 1.4 Host tests — no hardware needed

Every module with no ESP-IDF dependency is tested on the Mac with plain `cc`.
Run these before every commit and after every parameter change:

```bash
cd /Volumes/Projects/OMNIS/omnis-superloop-mvp && ./test/run_host_tests.sh
```

Expect `ALL 7 HOST TEST SUITES PASSED`. The runner exits non-zero if any suite
fails, so a single failure cannot hide behind later passes.

### 1.5 Useful variations

```bash
cd /Volumes/Projects/OMNIS && idf.py -C omnis-superloop-mvp fullclean build
```

```bash
cd /Volumes/Projects/OMNIS && idf.py -C omnis-superloop-mvp -p /dev/cu.usbmodem101 monitor
```

```bash
cd /Volumes/Projects/OMNIS && idf.py -C omnis-superloop-mvp size-components
```

---

## 2. Superloop architecture and workflow

### 2.1 The rule that shapes everything

**No FreeRTOS primitive appears in OMNIS-authored code.** No `xTaskCreate`, no
queues, semaphores, mutexes, event groups or software timers. ESP-IDF driver
internals are treated as hardware: if the I²C or RMT driver uses an RTOS object
inside itself, that is the driver's business.

The rule is verified mechanically rather than trusted: neither the `main/`
sources nor the undefined symbols of the compiled `libmain.a` contain any
FreeRTOS task, queue, semaphore, event-group, timer or port symbol.

The consequence is that **the entire application is one `for (;;)` loop**, and
ordering is explicit rather than emergent. There is no scheduler to blame and
no priority inversion to debug; the cost is that every slow operation must be
made non-blocking by hand.

### 2.2 Timing

```
GPTimer, 1 MHz, alarm every 2000 counts
        │
        └─► ISR: g_tick_500hz = true;        ← that is the entire ISR
                 (plus a missed-tick counter)
        │
   tick_wait()  spins until the flag is set, clears it, returns the
                microseconds of headroom that were left over
```

500 Hz, so **2000 µs per tick**. The ISR does nothing but set a `volatile bool`
— no I²C, no floating point, no logging. All real work happens in the loop body
when it sees the flag.

`tick_wait()` returns the **headroom**: how long the loop was idle before the
tick arrived. That single number is the loop's health indicator. It is reported
once a second, along with the count of ticks that were missed entirely
(*overruns*). On the Stage 1 hardware run the loop used ~2 µs of the 2000 µs
budget with zero overruns.

The main task is pinned to **CPU1** (`CONFIG_ESP_MAIN_TASK_AFFINITY_CPU1=y`)
and CPU1's idle-task watchdog is disabled — a superloop never yields, so the
idle task never runs, and the watchdog would otherwise fire immediately. CPU0
keeps running the Wi-Fi/BT stack idle work and the IDF's own housekeeping.

### 2.3 The loop body

```
   app_main
     ├── gpio_safe_state()        STEP low FIRST — the drivers are already live
     ├── params defaults + validate
     ├── kinematics_selftest()    the verified cases, re-run on the FPU
     ├── peripheral bring-up      I2C, both MPU6050s, UART1/CRSF, RMT, buzzer
     ├── boot IMU calibration     holds the loop; radio and buzzer still serviced
     └── for (;;)
          │
          │  tick_wait()  ────────────────────────── blocks here until the tick
          │
          ├── 1. SENSE
          │      imu_update()      2× MPU6050 over I²C  →  mount correction
          │                        →  gyro bias  →  per-IMU EKF  →  fusion
          │      crsf_poll()       UART1 RX  →  CRSF parser  →  16 channels
          │                        →  rc_input  →  sticks, switches, arm request
          │
          ├── 2. JUDGE
          │      fault latch       IMU comm · IMU disagreement >15° · link loss
          │                        · tilt · loop overrun
          │      supervisor        DISARMED / ARMED-FLAT / BALANCE-SETTLE /
          │                        ARMED-BALANCE, and which wheel pair
          │
          ├── 3. ACT
          │      flat mode:     sticks → IK → common clamp → deadband → slew
          │      balance mode:  lean PID in the balance frame → one wheel pair
          │      otherwise:     step_gen_stop()
          │                        ↓
          │      step_gen_update()   queues ~2 ms RMT bursts per wheel;
          │                          the RMT driver's ISR chains them
          │
          └── 4. REPORT
                 buzzer_service()   every tick
                 telemetry          one line per second
```

**Why this order.** Sense before judge, judge before act: a fault raised this
tick stops the motors this tick, not next. Reporting last so the telemetry line
describes the decision that was actually taken. The blocking UART cost of the
telemetry line is excluded from the timing statistics and from the overrun
fault, so printing can never fault the loop it is measuring.

**I²C never runs in an ISR.** The IMU reads are ordinary blocking transactions
in the loop body, which is why the 2000 µs budget matters and why
`OMNIS_IMU_READ_ALTERNATE` exists as an escape hatch (read one IMU per tick,
each filter then running at 250 Hz on its own measured `dt`).

### 2.4 How STEP pulses actually get out

This is the part that would normally want a task, and does not have one.

Each wheel owns one of the ESP32-S3's four RMT TX channels. Every tick,
`step_gen_update()` tops up that channel's queue with short bursts (~2 ms) of
STEP pulses generated at the wheel's current rate; the RMT driver's own ISR
chains them back-to-back. **Nothing of ours runs in the pulse hot path.**

- **Queue regulation is exact, not estimated.** Pending chunks = submitted in
  the loop minus completed in the RMT done-callback. A late tick is absorbed by
  the ~6 ms lead; the next tick refills it.
- **Direction reversals drain first.** Chunks already queued were generated for
  the old direction, so a reversal stops queueing, lets the queue empty, sets
  `DIR`, waits a full tick, then resumes. The deadband has already held the
  wheel near zero by then, so the few-millisecond pause is invisible.
- **Stopping means "no more pulses"** — Rev 2.0 has no enable line.
  `step_gen_stop()` neutralises the level bits of every queued chunk in place;
  the copy encoder reads payloads lazily, so unencoded chunks play as silence.
  At most one chunk already inside RMT memory still plays. (`rmt_tx_disable()`
  was rejected: it recycles only the in-flight transaction, with no done
  callback, and leaves the rest queued to play on the next enable.)

### 2.5 Failsafe behaviour

Because `EN#` is hardwired, "safe" means **stopped and holding**, not limp:

| Condition | Result |
|---|---|
| Radio link lost | STEP pulses cease; motors hold position; buzzer sounds |
| IMU comm failure or >15° disagreement | Fault latched, disarmed, pulses cease |
| Tilt past the mode's limit | Fault latched, disarmed |
| Loop overruns past the window threshold | Fault latched while armed |
| Parameters or tick invalid at boot | Never arms; `fault_only_loop()` explains itself every 2 s |

Re-arming always requires the arm switch to be **cycled LOW→HIGH**. The
supervisor consumes the edge, so a fault that clears while the switch is still
up does not re-arm the robot on its own.

---

## 3. File index

Every file in `omnis-superloop-mvp/`, and what it is responsible for.

### 3.1 Project root

| File | Responsibility |
|---|---|
| `CMakeLists.txt` | Top-level ESP-IDF project definition |
| `sdkconfig.defaults` | The configuration that matters, in version control: CPU1 affinity, idle-WDT disable, FPU, log level. Delete `sdkconfig` to regenerate from it |
| `sdkconfig` | Generated. Not the source of truth |
| `README.md` | One-page overview and stage status |
| `OPERATIONS_GUIDE.md` | This file |
| `TESTING.md` | Bench bring-up procedure, stage by stage |
| `BUILD-LOG.md` | Construction history: what was built, what broke, what was learned. Also the scope, the settled decisions and the commit table, absorbed from `PLAN.md` |

The project info file is **not** duplicated here — there is one copy for the
whole project at [`../assets/documentation/omnis-info.md`](../assets/documentation/omnis-info.md),
carrying the full specification with `> **Superloop MVP:**` notes on what this
build actually does.

### 3.2 `main/` — configuration and support

| File | Responsibility |
|---|---|
| `CMakeLists.txt` | Source list and component requirements |
| `main.c` | Boot sequence, safe GPIO state, self-checks, the superloop itself, telemetry, and the bench pattern |
| `omnis_pins.h` | Board **Rev 2.0** GPIO map, traced from the KiCad schematic wire-by-wire rather than read off a drawing |
| `omnis_config.h` | Build-time switches (§5.1). Edit, rebuild, reflash |
| `omnis_params.{c,h}` | Every runtime-tunable number in one struct, with defaults and a validator. Stands in for the future `params.json` |
| `omnis_time.h` | Time helpers for a build with no RTOS delay primitives |

### 3.3 `main/` — timing

| File | Responsibility |
|---|---|
| `tick.{c,h}` | The 500 Hz GPTimer, its ISR (sets one flag), `tick_wait()`, headroom and overrun accounting |

### 3.4 `main/` — sensing and estimation

| File | Responsibility |
|---|---|
| `mpu6050.{c,h}` | Register-level MPU6050 driver on the ESP-IDF v6 `i2c_master` API |
| `mpu6050_regs.h` | Register map, configuration values, and the **pure** burst parser (host-tested) |
| `imu.{c,h}` | Both IMUs end to end: I²C bring-up, boot gyro-bias calibration with stillness gating, per-tick read, mount correction, frames, and the mount wizard |
| `omnis_imu_mounting.h` | As-built mounting descriptors and corner labelling. The two modules are **antiparallel**; uncorrected they read ~20° apart and trip the disagreement fault at every boot |
| `attitude_ekf.{c,h}` | Per-IMU 4-state attitude EKF. Byte-identical to `assets/control/` |
| `imu_fusion.{c,h}` | Inverse-covariance fusion of the two estimates, the gravity-vector disagreement metric, and down-side detection. Byte-identical to `assets/control/` |

### 3.5 `main/` — radio

| File | Responsibility |
|---|---|
| `crsf_parser.{c,h}` | **Pure** CRSF byte-stream parser: framing, CRC-8/DVB-S2, 16×11-bit channel unpacking. No IDF, fully host-tested against golden frames |
| `crsf.{c,h}` | UART1 glue: RX-only, non-blocking, 420000 baud, with RX-pin auto-detect |
| `rc_input.{c,h}` | Channels → sticks, switches and the arm request. Deadzone, centring checks, link-quality floor |

### 3.6 `main/` — drivetrain

| File | Responsibility |
|---|---|
| `mecanum_kinematics.{c,h}` | Inverse and forward kinematics for the **lateral parallel roller** layout, the roller-handedness constants, clamp, deadband and the slip metric. Byte-identical to `assets/kinematics/` |
| `drive.{c,h}` | Sticks → body velocity → wheel rates, in the one correct order, plus the acceleration slew limiter. Carries the ordering rationale in its header |
| `step_wave.{c,h}` | **Pure** STEP waveform generator: rate in, RMT-style symbols out, with proven guarantees (pulses never split, every chunk ends LOW, rounding residue carried) |
| `step_gen.{c,h}` | RMT glue for four wheels: burst re-arm, exact queue regulation, direction-reversal drain, and stop-by-neutralising |

### 3.7 `main/` — control and safety

| File | Responsibility |
|---|---|
| `pid.{c,h}` | Discrete PID with derivative-on-measurement and conditional-integration anti-windup, plus the outer velocity-bias loop. Byte-identical to `assets/control/` |
| `balance.{c,h}` | Two-wheel balance controller. Lean in, wheel rates out. Its header carries the per-pair wheel-sign derivation |
| `fault.{c,h}` | The fault latch: what is wrong, how long it stays wrong, and which of the three clearing classes it belongs to |
| `buzzer_pattern.{c,h}` | **Pure** buzzer patterns and the priority rules that choose between them |
| `buzzer.{c,h}` | Buzzer GPIO over the pure pattern player |
| `supervisor.{c,h}` | The arming state machine: when the motors may move, in which mode, on which wheel pair, and why an arm request was refused |

### 3.8 `test/` — host tests, no hardware

| File | Covers |
|---|---|
| `run_host_tests.sh` | Runs every suite; non-zero exit if any fails |
| `test_kinematics.c` | IK/FK against the verified reference numbers, the layout's own properties (holonomy per axis, lever ratio, column non-orthogonality, null space), clamp, deadband, RC mapping, the full `drive_solve` pipeline and the slew limiter |
| `test_control.c` | EKF, fusion and PID |
| `test_crsf.c` | Parser and RC input, against golden frames |
| `test_mpu6050.c` | Burst decoder |
| `test_step_wave.c` | The waveform guarantees, on a reconstructed timeline |
| `test_supervisor.c` | Fault latch, buzzer patterns, arming state machine |
| `test_balance.c` | Balance signs, limits, and a closed-loop inverted-pendulum simulation on both pairs |
| `crsf_golden.h` | Reference frames from an independent implementation |

---

## 4. Tuning cheat sheet

Everything here is a **parameter**, not a code change. Edit
`main/omnis_params.c` (defaults) or `main/omnis_config.h` (build switches),
rebuild, reflash.

> Run `./test/run_host_tests.sh` after any parameter edit. Several suites assert
> on the defaults and will tell you immediately if a change contradicts them.

### 4.1 A wheel turns the wrong way — `motor.dir_invert[]`

```c
p->motor.dir_invert[0] = false;   /* FL */
p->motor.dir_invert[1] = false;   /* FR */
p->motor.dir_invert[2] = false;   /* RL */
p->motor.dir_invert[3] = false;   /* RR */
```

The left and right motors are mirror images across the chassis, so the same
*wheel* direction needs opposite shaft rotation on each side. Fix it **here**.

> **Never fix a backwards wheel by flipping a sign in the kinematics.** It will
> appear to work for that one motion and will silently break the IK→FK round
> trip and every other motion involving that wheel.

**Procedure:** command plain FORWARD first (TESTING.md §5.1) and set the flags
until all four wheels drive the robot forward. Only then look at strafe or yaw.

### 4.2 The robot strafes the wrong way — roller handedness

If **forward is correct on all four wheels** but strafe goes the wrong way, the
problem is not a `dir_invert` flag; it is the roller handedness. In
`main/mecanum_kinematics.h`:

```c
#define MECANUM_DELTA_FL   (-1)
#define MECANUM_DELTA_FR   (+1)
#define MECANUM_DELTA_RL   (-1)
#define MECANUM_DELTA_RR   (+1)
```

**Negate all four together** and rebuild. That is the complete fix — both `vy`
signs and both yaw lever arms are computed from these, and the forward
kinematics follows automatically.

**The test that tells you which it is** — wheels off the ground, both
directions:

| Command | Correct handedness | Mirrored handedness |
|---|---|---|
| `vx = vy` (forward-left diagonal) | **FL and RL** completely still | FR and RR still instead |
| `vx = −vy` (forward-right diagonal) | **FR and RR** completely still | FL and RL still instead |

If a *diagonal* pair idles instead of a side, the wheels are not in the
parallel layout at all and the derivation does not describe your robot. If
neither pattern appears, go back to §4.1 — forward motion is not right yet.

The bench pattern (`OMNIS_BENCH_STEP_TEST 1`) runs both diagonals for you.

### 4.3 Chassis dimensions — `geometry`

```c
p->geometry.wheel_radius_mm = 30.0f;
p->geometry.wheelbase_mm    = 223.0f;   /* L: front-to-back wheel CENTRES */
p->geometry.track_width_mm  = 230.0f;   /* W: left-to-right wheel CENTRES */
```

Measure wheel **centre to centre**, not the frame. No numeric geometry constant
appears anywhere in the kinematics, so these three numbers are the whole story.

What each one moves:

| Change | Effect |
|---|---|
| `wheel_radius_mm` | Scales every wheel rate inversely. A wrong radius makes all speeds wrong by the same ratio — easy to miss, since the robot still moves correctly, just faster or slower than commanded |
| `wheelbase_mm` (L) | Front yaw lever `(L+W)/2`, rear yaw lever `(L−W)/2`, **and** the forward-kinematics yaw scale, which depends on `L` alone |
| `track_width_mm` (W) | Both lever arms, and the strafe row of the forward kinematics |

**Two warnings specific to this drivetrain:**

- The rear yaw lever is `(L−W)/2` = **−3.5 mm** as built. It is 1.5% of the
  front lever, it is **zero on a square chassis**, and it **changes sign** if
  the robot is ever made longer than it is wide. Nothing breaks — but the rear
  wheels' direction during a spin is not a stable fact to rely on.
- The firmware's boot self-check runs on **fixed reference geometry**
  (30/223/230), deliberately, so that editing these values cannot mask a
  genuine kinematics fault.

### 4.4 Speed and yaw rate — `rc_scale`

```c
p->rc_scale.vx_max_mmps       = 300.0f;   /* full throttle            */
p->rc_scale.vx_secondary_mmps = 150.0f;   /* pitch stick, additive    */
p->rc_scale.vy_max_mmps       = 300.0f;   /* full roll, + = LEFT      */
p->rc_scale.w_max_radps       = 1.5f;     /* full yaw,  + = CCW       */
```

These are derived, not guessed. With `max_step_rate = 7000`:

```
pure vx :  f = vx · 509.2958 / r = 16.98 · vx      →  ceiling 412 mm/s
pure vy :  same cost as vx                         →  ceiling 412 mm/s
pure w  :  f = k · w · 509.2958 / r = 3845 · w     →  ceiling 1.82 rad/s
```

The defaults sit ~27% below each ceiling so that *combined* commands have
headroom before the clamp bites. Raising one of these does not make the robot
faster past the clamp — it just makes the common-factor clamp engage sooner and
scale the whole motion down.

**Stick polarity** belongs here and nowhere else:

```c
p->rc_scale.invert_throttle = false;
p->rc_scale.invert_pitch    = false;
p->rc_scale.invert_roll     = false;   /* set if stick-LEFT reads negative */
p->rc_scale.invert_yaw      = false;   /* set if stick-LEFT reads negative */
```

### 4.5 Stepper limits — `step`

```c
p->step.max_step_rate      = 7000.0f;    /* per-wheel cap [µsteps/s]  */
p->step.deadband_steps     = 20.0f;      /* below this, hold stopped  */
p->step.max_accel_steps_s2 = 20000.0f;   /* slew limit                */
```

| Parameter | Raise it if | Lower it if |
|---|---|---|
| `max_step_rate` | You need more top speed **and** the motors are not skipping | Wheels stall or buzz at speed. 7000 µsteps/s ≈ 131 RPM, already well off a NEMA17's 12 V torque curve |
| `deadband_steps` | Wheels chatter or buzz when nearly stopped | A genuine crawl command is being swallowed |
| `max_accel_steps_s2` | Response feels sluggish | The robot loses steps when the stick snaps — the **only** defence against that, since there are no encoders |

`max_accel_steps_s2` is a deliberately conservative placeholder. The right value
depends on the `Vref` current limits, which are set on the bench.

> **Expected, not a fault:** during a slow yaw command the **rear pair sits
> still** while the front pair drives. Their yaw lever is 1.5% of the front's,
> so below about **0.34 rad/s** they fall under the deadband. Raising
> `deadband_steps` makes this happen at higher yaw rates.

### 4.6 STEP electrical timing — `motor`

```c
p->motor.step_pulse_us    = 10;   /* STEP high time; A4988 minimum is 1 µs */
p->motor.step_min_low_us  = 10;   /* floor on the low time between pulses  */
```

10 µs each is generous and deliberately so — it is robust to wiring capacitance
on a hand-built board. Both feed `step_wave.c`, which enforces the guarantees
that pulses are never split and every chunk ends LOW. `step_gen_init()` refuses
a `max_step_rate` above what the symbol buffer can express at these timings, so
an inconsistent pair fails loudly at boot rather than producing short chunks.

### 4.7 Balance gains — `balance`

Gains are **zero by default**, and the supervisor refuses to arm balance mode
until `kp > 0`. That is intentional: a zero-gain balancer simply falls over.

```c
p->balance.kp                = 0.0f;        /* start here */
p->balance.ki                = 0.0f;
p->balance.kd                = 0.0f;
p->balance.integral_max      = 0.0f;
p->balance.trim_rad          = 0.0f;        /* static lean offset      */
p->balance.lean_limit_rad    = 0.10472f;    /* 6°  — total target clamp */
p->balance.stick_lean_max_rad= 0.0523599f;  /* 3°  — full pitch stick   */
p->balance.turn_max_steps    = 600.0f;      /* full roll → differential */
p->balance.max_wheel_accel   = 60000.0f;    /* PID output clamp         */
p->balance.tilt_fault_rad    = 0.6108652f;  /* 35° — declared fallen    */
p->balance.output_invert     = false;
p->balance.vel_bias_gain     = 0.0f;        /* outer loop OFF by default */
```

Tune in this order (TESTING.md §7.4): `kp` until it oscillates, back off, then
`kd` to damp, then a little `ki` only if it drifts. `OMNIS_TUNE_KP_FROM_POT`
(§5.1) lets the S1 slider sweep `kp` live without resetting the integrators.

> **`output_invert` is not a general-purpose fix.** If the wheels drive *away*
> from the fall on **both** wheel pairs, set it. If **only one** pair is wrong,
> stop — that means the per-pair wheel-sign derivation in `balance.h` does not
> match your hardware, and the flag would hide the problem rather than fix it.

### 4.8 Radio — `channel_map`, `rc`

```c
p->channel_map.throttle   = 1;   p->channel_map.pitch        = 2;
p->channel_map.roll       = 3;   p->channel_map.yaw          = 4;
p->channel_map.kill_switch= 6;   /* ARM: HIGH = permitted, LOW/MID = never */
p->channel_map.drive_mode = 8;   /* LOW flat · MID balance · HIGH auto     */
p->channel_map.speed_limiter = 9;
p->channel_map.tune_pot      = 10;
p->channel_map.arm_switch_invert = false;
```

```c
p->rc.crsf_baud        = 420000u;  /* ExpressLRS default for CRSF        */
p->rc.stick_deadzone   = 0.04f;    /* rescaled, not just zeroed          */
p->rc.center_tolerance = 0.10f;    /* arming needs every stick this close */
p->rc.pin_probe_ms     = 1500u;    /* no frames -> try the other RX pin  */
p->rc.min_link_quality = 0u;       /* uplink LQ floor [%]; 0 disables    */
```

Channel order varies by transmitter model and mode. Read the live channel dump
in the telemetry (TESTING.md §4.1) and set the map to match rather than
re-mapping in the transmitter.

### 4.9 Safety thresholds — `imu`, `safety`

```c
p->imu.disagree_thresh_rad      = 0.2617994f;  /* 15° — the two IMUs disagreeing  */
p->imu.flat_tilt_fault_rad      = 0.7853982f;  /* 45° — armed flat and tipped     */
p->imu.comm_fail_reads          = 25u;         /* consecutive failed I²C reads    */
p->imu.frozen_reads             = 50u;         /* identical bursts = stuck sensor */
p->imu.cal_samples              = 1000u;       /* boot gyro-bias samples (2 s)    */
p->imu.cal_gyro_std_max_radps   = 0.02f;       /* stillness gate                  */

p->safety.upright_min_rad       = 1.0471976f;  /* 60° — standing on a wheel pair  */
p->safety.arm_flat_max_tilt_rad = 0.5235988f;  /* 30° — flat mode arms below this */
p->safety.balance_settle_ms     = 400u;        /* hold still while filters settle */
p->safety.overrun_window_ticks  = 500u;        /* one second at 500 Hz            */
p->safety.overrun_fault_count   = 25u;         /* overruns per window that fault  */
```

The validator enforces `upright_min_rad > arm_flat_max_tilt_rad`, so the two
modes can never both claim the same pose.

Loosen the 15° disagreement threshold only after confirming the IMU **mounting
descriptors** are right (TESTING.md §3.3 has a wizard that derives them from two
poses). A mounting error looks exactly like a disagreement fault, and widening
the threshold to "fix" it throws away the redundancy that justifies two IMUs.

---

## 5. Build-time switches

### 5.1 `main/omnis_config.h`

| Switch | Default | Effect |
|---|---|---|
| `OMNIS_TICK_RATE_HZ` | `500` | Superloop rate. Everything timing-related derives from it |
| `OMNIS_I2C_SCL_HZ` | `400000` | I²C clock. Lower it if the bus is marginal on a hand-built board |
| `OMNIS_IMU_READ_ALTERNATE` | `0` | `1` = read one IMU per tick, halving I²C time; each filter then runs at 250 Hz on its own `dt`. Use if the loop overruns |
| `OMNIS_RUN_MOUNT_WIZARD` | `0` | `1` = boot into the two-pose procedure that derives the IMU mounting constants and prints them to paste in. Never arms in this mode |
| `OMNIS_BENCH_STEP_TEST` | `0` | `1` = ignore the radio and cycle fixed motions through the real pipeline. **WHEELS OFF THE GROUND** — it starts ~3 s after boot whether or not anyone is watching |
| `OMNIS_TELEMETRY_ENABLED` | `1` | The once-a-second status line |
| `OMNIS_TELEMETRY_IN_BALANCE` | `0` | `1` = keep printing while balancing. A blocking log line every second is a periodic disturbance to a balance loop; off by default, with a summary printed on disarm instead |
| `OMNIS_TUNE_KP_FROM_POT` | `0` | `1` = the S1 slider sweeps balance `kp` live, without resetting integrators |

### 5.2 `sdkconfig.defaults` — the ones that matter

| Option | Why |
|---|---|
| `CONFIG_ESP_MAIN_TASK_AFFINITY_CPU1=y` | The superloop owns CPU1; CPU0 keeps the IDF's housekeeping |
| `CONFIG_ESP_TASK_WDT_CHECK_IDLE_TASK_CPU1=n` | A superloop never yields, so CPU1's idle task never runs and the watchdog would fire immediately |

To regenerate `sdkconfig` from these, delete it and rebuild.

---

## 6. Troubleshooting index

| Symptom | Start at |
|---|---|
| Won't flash / won't connect | §1.3 — BOOT + RESET |
| Boot halts, buzzer repeating, log every 2 s | Parameters or tick invalid. The log names which |
| `kinematics self-check … *** FAIL ***` | The FPU or the port, not your parameters — the check uses fixed reference geometry |
| Disagreement fault at every boot | IMU mounting descriptors. TESTING.md §3.3 wizard — do **not** widen the threshold |
| One wheel backwards | §4.1 `dir_invert` |
| Forward fine, strafe backwards | §4.2 roller handedness — negate all four |
| Rear wheels don't turn during slow spins | **Expected.** §4.5 — their lever is 1.5% of the front's |
| All four wheels spin equally fast during a pure yaw | Stale X-drive kinematics — the rear pair should crawl at ~59 steps/s per rad/s |
| Wheels chatter near zero | §4.5 `deadband_steps` |
| Steps lost when the stick snaps | §4.5 `max_accel_steps_s2` — lower it |
| Robot curves during a commanded strafe | Per-wheel clipping has crept in somewhere. The null-space metric in the telemetry should be ~0 |
| Loop overruns | §5.1 `OMNIS_IMU_READ_ALTERNATE`, or lower `OMNIS_I2C_SCL_HZ` if the bus is retrying |
| Balance falls away from the lean, both pairs | §4.7 `output_invert` |
| Balance falls away on **one** pair only | **Do not set `output_invert`.** `balance.h`'s wheel-sign derivation does not match your hardware |

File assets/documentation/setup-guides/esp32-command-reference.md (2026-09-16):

# ESP32-S3 / ESP-IDF Command Reference (OMNIS)

Quick lookup, not a tutorial. Assumes the native macOS **ESP-IDF v6.0.2** install at
`~/.espressif/v6.0.2/esp-idf`, project at `/Volumes/Projects/OMNIS`. See
`phase0-toolchain-environment.md` for the setup story and gotchas behind these commands,
including §9's post-mortem of the v5.3.1 → v6.0.2 migration.

## Every new terminal session — do this first

```bash
. ~/.espressif/tools/activate_idf_v6.0.2.sh
```

```bash
idf.py --version      # sanity check — should print: ESP-IDF v6.0.2
```

Required once per terminal tab/window/SSH session. Not persistent, not global — see
Phase 0 doc §4 for why.

> **Use the activation script, not `export.sh`.** `export.sh` looks for a Python 3.11
> virtualenv while this install runs on 3.14, so it fails where the activation script
> works. The old `get_idf` alias pointed at the removed v5.3.1 tree — drop it.

---

## Finding the board

```bash
ls /dev/cu.*                    # list all serial devices
```
Run with board unplugged, then plugged in, diff the two lists. The new entry is your
port. Typical patterns:
- `/dev/cu.SLAB_USBtoUART` — CP210x-based boards
- `/dev/cu.usbserial-*` or `/dev/cu.wchusbserial*` — CH340-based boards

Once known, worth exporting for convenience in a session:
```bash
export ESPPORT=/dev/cu.<your-port>     # lets you drop -p <port> from idf.py commands below
```
(Session-scoped too — same caveat as `get_idf`.)

---

## Build / flash / monitor

```bash
idf.py build                          # compile only, no flash
idf.py -p $ESPPORT flash              # flash only, no monitor
idf.py -p $ESPPORT monitor            # open serial monitor only (board must already be flashed)
idf.py -p $ESPPORT flash monitor      # flash, then immediately open monitor — most common
idf.py -p $ESPPORT app-flash          # flash ONLY the app partition, skip bootloader/partition-table — faster iteration once those are stable
```

Inside the monitor:
- `Ctrl+]` — exit monitor, return to shell
- `Ctrl+T` then `Ctrl+H` — show monitor's own help/shortcut menu (chord, not simultaneous)
- `Ctrl+T` then `Ctrl+R` — reset the board without leaving the monitor

---

## Reconnecting to an already-flashed board

If the board is already flashed and running (or was power-cycled, restarted itself, etc.)
and you just want to see its serial output without reflashing:

```bash
idf.py -p $ESPPORT monitor
```
No `build` or `flash` needed — this just opens the serial connection. Safe to run
repeatedly; won't disturb what's already running on the chip.

To force a fresh boot without reflashing (e.g. after a monitor session where you want to
see the startup log again from the top):
```bash
idf.py -p $ESPPORT monitor          # then Ctrl+T, Ctrl+R inside it to trigger a reset
```

---

## Cleaning / reconfiguring

```bash
idf.py fullclean                # wipes build/ entirely — use when switching targets or after suspicious build errors
idf.py reconfigure              # re-runs CMake configure step without a full clean
idf.py set-target esp32s3       # (re)writes sdkconfig for the S3 — only needed once per project, or after fullclean
```

---

## Inspecting the build

```bash
idf.py size                     # summary: flash/RAM usage totals
idf.py size-components          # breakdown by component (freertos, lwip, your main app, etc.)
idf.py size-files               # breakdown by individual source file
idf.py docs                     # opens relevant ESP-IDF docs page in browser
```

---

## menuconfig (sdkconfig editor)

```bash
idf.py menuconfig
```
Relevant categories for this project (see Phase 0 doc §7 for what's not yet explored
here):
- `Component config → ESP PSRAM` — enable, N16R8 variant has 8MB PSRAM
- `Component config → FreeRTOS` — tick rate, task stack sizing defaults
- `Partition Table` — flash layout for firmware vs. logging/data storage

---

## esptool.py — lower-level than idf.py flash

`idf.py flash` wraps `esptool.py`; these are for when you need something idf.py doesn't
expose directly.

```bash
esptool.py --port $ESPPORT chip_id           # confirm chip identity/revision
esptool.py --port $ESPPORT flash_id          # confirm flash chip info (size, manufacturer)
esptool.py --port $ESPPORT read_flash 0x0 0x1000 partition_dump.bin   # read raw bytes from flash, e.g. partition table region
esptool.py --port $ESPPORT erase_flash       # full chip erase — wipes everything, including NVS data
```

---

## Crash / panic debugging

```bash
idf.py -p $ESPPORT monitor      # panics auto-decode here IF build/ has the matching .elf
```
Look for `Guru Meditation Error: Core X panic'ed (<reason>)` — this is a real fault, not
a clean restart. Compare against a clean restart's reset reason
(`RTC_SW_CPU_RST`/`POWERON_RESET`/etc. with a single-frame trace to something like
`esp_restart_noos`) — see Phase 0 doc §6b for a worked example of telling these apart.

Manual backtrace decode, if the monitor doesn't auto-resolve an address for some reason:
```bash
xtensa-esp32s3-elf-addr2line -pfiaC -e build/OMNIS.elf <address>
```

---

## Git hygiene for this project (minimum)

```bash
# .gitignore should include at minimum:
build/
sdkconfig.old
managed_components/
```
`sdkconfig` itself is generally committed (project-specific config); `sdkconfig.old` is
an auto-generated backup and should not be.

---

## JTAG / OpenOCD (awareness only — not yet set up)

```bash
openocd -f board/esp32s3-builtin.cfg     # example only — exact config depends on debug probe/wiring, not yet exercised on this project
xtensa-esp32s3-elf-gdb build/OMNIS.elf   # then connect to OpenOCD's gdb stub from within
```
Flagged in Phase 0 doc §7 as deferred — listed here for when it becomes relevant.

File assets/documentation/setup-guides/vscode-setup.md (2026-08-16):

# VS Code Setup Guide — OMNIS (ESP32-S3 + ESP-IDF + FreeRTOS)

This assumes VS Code is already installed on your machine — no VS Code install step here, this starts directly from extensions.

## 1. Prerequisites (OS-level)

Before touching VS Code, make sure your system has:

- **Git** installed and on PATH (`git --version` to check)
- **Python 3.9+** installed and on PATH (`python3 --version`) — ESP-IDF's tooling depends on this
- On Windows: enable long path support if you haven't (ESP-IDF's toolchain has deep nested paths)
- USB driver for your EdgeHax S3 Pro board's USB-C-to-serial chip (usually CP210x or CH340 — check the board's docs; Windows sometimes needs the driver installed manually, Linux/macOS usually don't)

## 2. Install the Core Extensions

Open the Extensions panel (`Ctrl+Shift+X` / `Cmd+Shift+X`) and install:

1. **Espressif IDF** (publisher: Espressif Systems) — this is the big one. It bundles ESP-IDF (the framework), the Xtensa/RISC-V toolchains, and **FreeRTOS comes with it automatically** since ESP-IDF is built on top of FreeRTOS.
2. **C/C++** (publisher: Microsoft) — IntelliSense, debugging, go-to-definition for your C code. The IDF extension will prompt to install this if missing.
3. **C/C++ Extension Pack** (optional but convenient — bundles CMake Tools, which ESP-IDF's build system uses under the hood, useful if you want to inspect the CMake side directly)
4. **GitLens** (optional) — richer git history/blame view, useful once the repo has some commits
5. **Better C++ Syntax** (optional, cosmetic — improves highlighting for modern C/C++ features)

## 3. Run the ESP-IDF Setup Wizard

1. `Ctrl+Shift+P` → type "ESP-IDF: Configure ESP-IDF Extension" → Enter
2. Choose **Express** setup for the first install (Advanced lets you point to an existing IDF install, not needed on a fresh machine)
3. Pick the ESP-IDF **version** — use the latest stable release (avoid `master`/dev branches for a portfolio project; you want stability, not bleeding-edge features)
4. Let it download: this pulls the IDF source, the Xtensa toolchain (needed for ESP32-S3, which is Xtensa LX7-based), and a dedicated Python virtual environment. This step is large (~1–2GB) and can take a while depending on your connection
5. Once it finishes, the status bar at the bottom of VS Code should show the ESP-IDF version and a few new icons (build, flash, monitor, etc.)

## 4. Create/Open the OMNIS Project

- New project: `Ctrl+Shift+P` → "ESP-IDF: New Project" → pick a template (start from `template-app` or `hello_world` and strip it down) or, once you have your GitHub repo, just `git clone` it and open the folder in VS Code
- Set the target chip: `Ctrl+Shift+P` → "ESP-IDF: Set Espressif Device Target" → select **esp32s3**
- Select the serial port for your EdgeHax S3 Pro board via the bottom status bar port selector (or `Ctrl+Shift+P` → "ESP-IDF: Select Port to Use")

## 5. Build / Flash / Monitor Workflow

These are the commands you'll use constantly, available both as bottom-status-bar icons and command-palette entries:

| Action | Command Palette | Status Bar Icon |
|---|---|---|
| Build | ESP-IDF: Build your Project | 🔧 |
| Flash | ESP-IDF: Flash your Project | ⚡ |
| Monitor (serial console) | ESP-IDF: Monitor your Device | 🔌 |
| Build+Flash+Monitor combined | ESP-IDF: Build, Flash and Start a Monitor on your Device | ▶ (play icon) |

`Ctrl+]` inside the monitor exits it back to the terminal.

## 6. Quick Sanity Check

Before changing anything else, build and flash a stock `hello_world` example first. This confirms the toolchain, board, and serial port are all correctly wired up before you start layering your own kernel or logic on top of it.

## 7. Project Configuration (sdkconfig)

`Ctrl+Shift+P` → "ESP-IDF: SDK Configuration Editor (menuconfig)" opens a searchable GUI over `sdkconfig`. Relevant early settings for OMNIS:

- **Component config → ESP PSRAM** → enable, since the N16R8 variant has 8MB PSRAM you'll want available
- **Component config → FreeRTOS** → FreeRTOS-specific tuning (tick rate, task stack sizes, etc.)
- **Partition Table** → revisit once you decide how much flash to reserve for logging/data vs. firmware, given the 16MB flash

## 8. Git / GitHub Setup

VS Code has git built in (no extension needed for basics):

1. `Ctrl+Shift+P` → "Git: Clone" if starting from the GitHub repo, or "Git: Initialize Repository" if starting local-first and pushing up later
2. Source Control panel (`Ctrl+Shift+G`) handles stage/commit/push visually
3. If you haven't set global git identity yet: `git config --global user.name "..."` and `git config --global user.email "..."` in the integrated terminal
4. Add a `.gitignore` — for ESP-IDF projects, at minimum ignore `build/`, `sdkconfig.old`, and `managed_components/` if you end up using the component manager

## 9. Learning FreeRTOS Alongside This Project

A practical path once the base project builds:

1. Start with basic `xTaskCreate` calls to get a feel for tasks vs. a bare-metal loop
2. Move to queues (`xQueueSend`/`xQueueReceive`) — maps directly onto the uORB-style pub/sub messaging planned for OMNIS
3. Then semaphores/mutexes for shared resource protection (e.g., the shared I2C bus between both MPU6050s and the LCD)
4. Espressif's own FreeRTOS SMP docs are worth reading since the S3 is dual-core — task-to-core pinning (`xTaskCreatePinnedToCore`) will matter for keeping the control loop deterministic

## 10. Vendoring Your Own FreeRTOS Kernel (Optional, Advanced)

For deeper learning, the FreeRTOS-LTS kernel downloaded directly from the FreeRTOS website can be swapped in as a custom ESP-IDF component instead of relying solely on the version bundled inside ESP-IDF. This step is optional — the project builds fine without it — but it's the way to actually study and run the exact kernel source rather than the version buried inside the SDK install.

1. **Create the component folder** — inside the OMNIS project, next to `main/`, create `components/freertos/`. ESP-IDF auto-discovers anything in `components/`, and a component named exactly `freertos` there takes priority over the one bundled inside the SDK.
2. **Copy in the kernel source** — from the downloaded zip's `FreeRTOS-Kernel/` folder, copy `tasks.c`, `queue.c`, `list.c`, `timers.c`, `event_groups.c`, `stream_buffer.c`, and the `include/` headers into the new component. Also copy `portable/ThirdParty/GCC/Xtensa_ESP32/` (the CPU port) and one file from `portable/MemMang/` — `heap_4.c` is the standard choice.
3. **Write the component's CMakeLists.txt** — register the sources with `idf_component_register(SRCS ... INCLUDE_DIRS ...)`, and list `REQUIRES hal soc esp_hw_support esp_timer esp_rom esp_system` in it. The port files' `#include "hal/..."` and `"soc/..."` lines still resolve against the installed ESP-IDF — this swaps the kernel, not the whole HAL.
4. **Clean rebuild and read every error** — the likely friction point is version drift, since this LTS kernel snapshot may expect slightly different hal/soc function signatures than the installed ESP-IDF version. Working through those mismatches by hand is where the real learning happens.
5. **Prove the swap works before building on it** — flash a minimal test (two tasks toggling an LED or printing to serial on independent timers) to confirm real context-switching before writing any OMNIS-specific logic on top.

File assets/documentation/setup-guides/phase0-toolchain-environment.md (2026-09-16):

# Phase 0 — Toolchain & Environment (OMNIS)

Status markers used below:
- ✅ Verified — you personally ran this and confirmed the output
- ⬜ Not yet done — written from spec, do this yourself before calling Phase 0 complete

---

## 0. Two separate environments exist for this project — know which one you're in

| | VS Code Devcontainer (`.devcontainer/`) | Native macOS install |
|---|---|---|
| IDF version | v6.1-dev (dev branch) | **v6.0.2** (stable) — was v5.3.1 until the §9 migration |
| Can reach physical EdgeHax S3 Pro board? | **No** — no `/dev/ttyUSB*`/`/dev/ttyACM*` passthrough configured, only Linux virtual consoles | Yes, via macOS `/dev/cu.*` |
| Purpose | QEMU emulation (`qemu-system-xtensa` is installed), isolated FreeRTOS experiments | Primary environment — all real hardware work: build, flash, monitor |
| Requires | Docker Desktop running + "Dev Containers" extension (`ms-vscode-remote.remote-containers`) installed | Nothing beyond steps below |

**Rule going forward: all real board work happens natively. The container is optional, for later QEMU experiments only.**

---

## 1. Prerequisites (native macOS)

```bash
git --version
python3 --version   # need 3.9+
```

✅ Confirmed: Python 3.11.0 present via the official python.org installer at
`/Library/Frameworks/Python.framework/Versions/3.11/`. A second install, Python 3.14, is
also present in `/Applications/`. Worth remembering if `idf.py` or `install.sh` ever
silently picks the wrong interpreter later — not an issue now, just a known fact about
this machine.

If Python/Git are missing on a fresh machine:
```bash
xcode-select --install        # gives you git
brew install python3          # prefer over relying on macOS system Python
```

---

## 2. Get the ESP-IDF SDK (separate from your project repo)

IDF is a ~2GB SDK — clone it *outside* your OMNIS project folder.

```bash
mkdir -p ~/esp
cd ~/esp
git clone -b v5.3.1 --recursive https://github.com/espressif/esp-idf.git
```

Pinned to `v5.3.1` (a stable release branch) deliberately — not `master`/dev. The
devcontainer runs a `-dev` branch; treat the two as intentionally different, not a bug to
reconcile. Mixing them casually will produce confusing version-specific bugs.

✅ Confirmed: clone completed, `esp-idf` directory present at `~/esp/esp-idf`.

---

## 3. Run the install script (pulls the Xtensa/RISC-V toolchains)

```bash
cd ~/esp/esp-idf
./install.sh esp32s3
```

**Only install the target(s) you actually own.** `./install.sh esp32s3` installs just the
S3 toolchain. Do **not** run `./install.sh all` (or bare `./install.sh`) — that pulls
toolchains for every Espressif chip (ESP32, S2, C2, C3, C5, C6, C61, H2, P4...), multiple
extra GB, zero benefit for a single-board project. Re-run with a new target later, if
you ever add a different chip — it's additive, not a locked-in decision.

Note: even for esp32s3, `install.sh` also pulls `riscv32-esp-elf` — this is correct and
expected, not a mistake. The S3's onboard ULP (low-power coprocessor) is RISC-V-based
even though the main CPU cores are Xtensa.

### Known failure mode: SSL certificate error

```
WARNING: Download failure: <urlopen error [SSL: CERTIFICATE_VERIFY_FAILED]
certificate verify failed: unable to get local issuer certificate (_ssl.c:992)>
...
ERROR: Failed to download, and retry count has expired
```

**Not a network problem.** Python installed via the official python.org `.pkg` ships its
own bundled CA store, which requires a one-time post-install script to populate. If that
script never ran, *no* HTTPS download from that Python will verify, ever, until fixed.

Fix, in order of preference:
```bash
# 1. Find which Python.org version folder you have:
ls /Applications/ | grep -i python

# 2. Run its cert installer (adjust version number to match):
/Applications/Python\ 3.11/Install\ Certificates.command

# 3. Fallback if step 2's folder doesn't exist (e.g. Homebrew Python):
/Library/Frameworks/Python.framework/Versions/3.11/bin/python3 -m pip install --upgrade certifi
```

✅ Confirmed on this machine: `Install Certificates.command` ran clean, `certifi` upgraded
2026.5.20 → 2026.7.22, symlink + permissions updated. Re-running `install.sh esp32s3`
afterward completed successfully — full toolchain + Python venv (esptool, esp-idf-monitor,
esp-coredump, etc.) installed with no further errors.

---

## 4. Source the environment (do this **every new terminal session**)

```bash
. ~/esp/esp-idf/export.sh
idf.py --version    # should print: ESP-IDF v5.3.1
```

✅ Confirmed working in macOS Terminal.app.

**Critical, non-obvious behavior confirmed by direct experience on this project:**
Sourcing `export.sh` only affects the *current shell process*. It is not global, not
per-machine, not per-project — it's per-terminal-tab. Opening a new terminal window, a
new VS Code integrated terminal tab, a new SSH session, etc. — each one is a fresh shell
with no memory of a previous `export.sh` call. `idf.py` will report
`zsh: command not found: idf.py` in every new session until you source it again there.

This was directly observed: `idf.py build` succeeded in Terminal.app (already sourced)
while the *same command in a freshly opened VS Code integrated terminal tab* failed with
`command not found`, despite being the same machine and same project folder open in both.

✅ Automated: after the sourcing-scoping issue was directly observed (see above — worked
in Terminal.app, failed with `command not found` in a freshly opened VS Code terminal
tab), an alias was added to `~/.zshrc`:

```bash
alias get_idf=". ~/esp/esp-idf/export.sh"
```

Applied with `source ~/.zshrc`, confirmed working in a brand-new terminal via
`get_idf && idf.py --version`. This is a *shortcut*, not full silent auto-sourcing —
`get_idf` must still be typed once per new terminal session. Deliberately not going
further to auto-source on every shell launch, since that would add overhead to every
terminal opened for unrelated work, not just ESP-IDF sessions.

---

## 5. Point the toolchain at the OMNIS project

```bash
cd /Volumes/Projects/OMNIS
idf.py set-target esp32s3
```

Rewrites `sdkconfig` for the S3 target; runs a CMake configure pass. Expect a short wait.
Confirm success by checking for `Build files have been written to...` in the output, and
that `sdkconfig`'s mtime updates (`ls -la sdkconfig`).

```bash
idf.py build
```

✅ Confirmed: clean build.
```
OMNIS.bin binary size 0x32a40 bytes. Smallest app partition is 0x100000 bytes. 0xcd5c0 bytes (80%) free.
Bootloader binary size 0x5260 bytes. 0x2da0 bytes (36%) free.
Project build complete. To flash, run:
  idf.py flash
```

---

## 6. Flash + monitor on real hardware

### 6a. Identify the board's serial port

```bash
ls /dev/cu.*
```
Run once with the EdgeHax S3 Pro **unplugged**, then again **plugged in**, and diff the
two lists by eye — the new entry that appears is your port. Don't guess the name from the
USB-serial chip datasheet; confirm it directly.

### 6b. Flash and open the monitor

```bash
idf.py -p /dev/cu.<your-port-here> flash monitor
```

`Ctrl+]` exits the monitor back to the shell.

✅ Confirmed: real board flashed and booted successfully. `hello_world` example ran end
to end — bootloader loaded, partition table read, app booted, `Hello world!` printed,
heap size reported (389836 bytes free), then the example's built-in 10-second countdown
triggered a clean self-restart, repeating.

**Important distinction actually observed at this step, worth keeping:** the restart
cycle produced output that *looks* like crash-decode output but isn't:
```
rst:0xc (RTC_SW_CPU_RST),boot:0x8 (SPI_FAST_FLASH_BOOT)
Saved PC:0x40375904
--- 0x40375904: esp_restart_noos at .../esp32s3/system_internal.c:158
```
`RTC_SW_CPU_RST` = software-requested clean restart (this example calls
`esp_restart()` on purpose after its countdown). The PC resolves to `esp_restart_noos`,
the normal restart routine — a single, expected frame, not a fault. This confirmed the
monitor's symbol resolution is working, but it is **not** the same thing as seeing a real
fault. Do not mistake a clean-restart trace for a crash trace — the reset-reason string
(`RTC_SW_CPU_RST` vs something like `Guru Meditation Error: ... panic'ed`) is the
tell.

### 6c. Crash decoding — ✅ CONFIRMED

Deliberately triggered a real fault: `int *bad_ptr = NULL; *bad_ptr = 42;` inserted into
`app_main()`. Result, read and understood line by line:

```
Guru Meditation Error: Core 0 panic'ed (StoreProhibited). Exception was unhandled.
...
PC : 0x42006781 ... app_main at .../hello_world_main.c:46
...
EXCVADDR: 0x00000000
...
Backtrace: 0x4200677e:... 0x42005f0b:... 0x4200bc92:...
--- 0x4200677e: app_main at hello_world_main.c:46
--- 0x42005f0b: main_task at .../app_startup.c:206
--- 0x4200bc92: vPortTaskWrapper at .../port.c:147
```

Key reading skills confirmed:
- `StoreProhibited` = illegal **write** (vs `LoadProhibited` = illegal read)
- `EXCVADDR` = the actual faulting address — `0x00000000` here confirmed this was
  genuinely the planted null-deref, not something else
- `PC` resolves directly to the source file/line of the fault when `idf.py monitor` has
  the matching `.elf` — no manual `addr2line` needed in the common case
- Backtrace reads bottom-to-top as a call stack: `vPortTaskWrapper` (FreeRTOS's generic
  task entry trampoline) → `main_task` (ESP-IDF's wrapper that invokes `app_main`) →
  `app_main` (the actual fault site). A deeper bug would show more frames.

**The distinguishing pattern vs. a clean restart (§6b), now confirmed by direct
comparison:** a real panic shows `Guru Meditation Error:` and a populated `EXCVADDR`
before any reset-reason line; a clean restart shows only a reset-reason line
(`RTC_SW_CPU_RST` etc.) resolving to an intentional function like `esp_restart_noos`,
with no panic block and no `EXCVADDR` at all. This is the check to run first on any
future unexpected reboot, before assuming anything else.

Crash line removed from `hello_world_main.c` after this exercise — file is back to the
stock example.

---

## 7. Deferred / explicitly not covered yet

These were named as Phase 0 scope but intentionally not exercised yet — listed so they
aren't silently forgotten, not because they're low priority:

- **6c above (real crash/panic + backtrace)** — highest priority remaining item, next
  session
- `menuconfig` navigation (`idf.py menuconfig`) — component config, FreeRTOS-specific
  settings (tick rate, minimal stack size)
- `idf.py monitor` keyboard shortcuts beyond `Ctrl+]`
- `xtensa-esp32s3-elf-gdb` / OpenOCD JTAG debugging (awareness only for now)
- `esptool.py` direct usage (`chip_id`, `flash_id`, reading partition tables) — separate
  from `idf.py flash`, which wraps it
- Git `.gitignore` conventions specific to ESP-IDF (`build/`, `sdkconfig.old`,
  `managed_components/`) — partially covered by the project's existing `.gitignore`,
  not yet reviewed line-by-line
- Vendoring the FreeRTOS-LTS kernel as a custom component (optional/advanced, shelved —
  reading kernel source via the installed copy at `$IDF_PATH/components/freertos/`
  achieves the same learning goal with no version-drift risk)

See `esp32-command-reference.md` (separate file) for a standing lookup of commands for
day-to-day board interfacing — this file stays a narrative/status record, that one is
the quick-reference.

---

## 8. Environment fingerprint (for future debugging reference)

- Machine: MacBook Air, macOS, Apple Silicon (arm64)
- **Native IDF: v6.0.2**, at `~/.espressif/v6.0.2/esp-idf` (not `~/esp/esp-idf` — that
  was an earlier v5.3.1 install, since removed; see §9 below for the full story)
- Project path: `/Volumes/Projects/OMNIS`
- Python: three installs present — 3.11.0, 3.14.0, and system/homebrew variants.
  `get_idf` alias explicitly forces `/Library/Frameworks/Python.framework/Versions/3.14/bin`
  to the front of PATH before sourcing `export.sh` — required, not optional, because
  plain `which python3` resolves 3.11 first on this machine and ESP-IDF v6.0.2's tooling
  needs the 3.14 venv specifically. See §9 for why this matters.
- Devcontainer IDF (separate, QEMU-only, untouched by any of this): v6.1-dev, target
  `esp32s3`, `qemu-system-xtensa` present at
  `/opt/esp/tools/qemu-xtensa/esp_develop_9.2.2_20260417/qemu/bin/`

## 9. Post-mortem: the v5.3.1 → v6.0.2 migration (read before repeating this)

What actually happened, briefly, because the specific failure modes are worth
remembering even though the end state is simple:

1. Discovered a **second, pre-existing IDF install** at `~/.espressif/v6.0.2/esp-idf`
   (dated Aug 10, predating this project's setup — almost certainly placed there
   silently by the VS Code Espressif extension at some point) was winning over the
   native `~/esp/esp-idf` v5.3.1 install on PATH.
2. Both installs share the same underlying tool cache (`~/.espressif/tools/`), and
   running `install.sh` for one can overwrite tool versions the other depends on —
   this produced `"tool X has no installed versions"` errors that looked like a broken
   install but were actually a version collision between the two checkouts.
3. Verified v6.0.2 as genuinely functional (clean `install.sh`, clean `export.sh`
   activation, clean project build) **before** deleting v5.3.1 — the correct order,
   confirmed working before removing the fallback.
4. After switching the `get_idf` alias to point at v6.0.2 and deleting `~/esp/esp-idf`,
   `export.sh` started failing in **every fresh terminal** with a missing-venv error —
   traced to `export.sh` picking up `python3.11` (first on this machine's PATH) instead
   of the `python3.14` that v6.0.2's tools were actually installed against. This is a
   different failure from #2 — not a version collision, a Python-interpreter-selection
   bug specific to how `export.sh` resolves `python3`.
5. Fixed durably by making the `get_idf` alias itself prepend the correct Python 3.14
   path before sourcing `export.sh`, rather than relying on the system default — see the
   current alias definition in §4 above.

**The lesson worth keeping, generalized:** a script that "just runs `python3`" is
implicitly depending on whatever your system's default PATH ordering happens to
resolve that to — which may silently differ from the interpreter that script's own
dependencies were actually installed against. If a `command not found` or
`venv not found`-style error reappears after a fix seemed to work, suspect the fix was
session-scoped (see the diagnostic playbook's Class 4) rather than assuming the earlier
fix failed to take effect at all.

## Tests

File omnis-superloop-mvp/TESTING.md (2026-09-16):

# OMNIS Superloop MVP — Bench Bring-Up and Testing

A step-by-step procedure for taking the firmware from a bare board to a
balancing robot, written to be followed without help. Each stage has what to
set up, what to do, what a pass looks like, and what the common failures mean.

**Do the stages in order.** Each one proves something the next one depends on.
Stage 1 was verified on hardware on 2026-09-07 (Rev 1 board); everything from
Stage 3 on has been built and host-tested but not yet run on a board.

---

## 0. Read this first — safety

**Board Rev 2.0 has no motor enable line.** All four A4988 `EN#` pins are
hardwired to GND. The consequences are not optional reading:

- **The motors are energised the moment 12 V is connected**, before the firmware
  even boots. They hold position and get warm. The only way to de-energise them is
  to **unplug the battery**. Keep the connector within reach.
- The firmware's "stop" means **no more STEP pulses**. Motors hold; they do not go
  limp. Nothing in software can make a stalled, energised motor safe — only
  unplugging can.
- **Set the A4988 current limits (Vref) before ever connecting 12 V.** With
  `EN#` hardwired, a wrong current limit starts cooking a motor or driver the
  instant power is applied. Set `Vref = Imax × 8 × Rsense` for the KV4239-T3B004's
  rated current, with margin (omnis-info.md §3f, §13c).
- **Wheels off the ground** for Stages 5 and 6. Chassis on a box, wheels free.
- **First driving tests on speed LOW** (speed switch down), in an open space.
- **Balance tests on a tether** or over something soft (Stage 7).

---

## 1. Toolchain, build, flash

Activate ESP-IDF v6.0.2. On this machine `export.sh` fails (it looks for a
py3.11 venv, the install is py3.14), so use the vendor script:

```bash
. ~/.espressif/tools/activate_idf_v6.0.2.sh
```

Build, flash and open the monitor (find the port with `ls /dev/cu.* | grep -v Bluetooth`):

```bash
cd /Volumes/Projects/OMNIS && idf.py -C omnis-superloop-mvp -p /dev/cu.usbmodem101 flash monitor
```

The console runs at **460800** baud; `idf.py monitor` picks that up automatically.
Exit the monitor with **Ctrl-]**. If the monitor shows garbage, set
`CONFIG_ESP_CONSOLE_UART_BAUDRATE=115200` in `sdkconfig.defaults`, delete
`omnis-superloop-mvp/sdkconfig`, and rebuild.

**After editing `sdkconfig.defaults`, always delete `omnis-superloop-mvp/sdkconfig`**
or the change is silently ignored.

Build-time switches live in `main/omnis_config.h`; tunable numbers live in
`main/omnis_params.c`. Every edit to either needs a rebuild and reflash.

---

## 2. Host tests — no hardware at all

Run these after any code change, before flashing anything:

```bash
cd /Volumes/Projects/OMNIS/omnis-superloop-mvp && ./test/run_host_tests.sh
```

It builds and runs every hardware-independent suite with plain `cc` and ends with
`ALL N HOST TEST SUITES PASSED`. Any failure exits non-zero. The expected values in
those suites came from independent references (the kinematics reference, a separate
Python CRSF implementation, published CRC check values) — if a test fails after a
change, the test is almost certainly right.

The control modules also have their own suite in `assets/control/`
(`./run_host_tests.sh` there).

---

## Stage 1 — Timing spine

**Setup:** USB only. **Battery disconnected.**

**Do:** flash and monitor. Leave it running 2–3 minutes.

**Pass:**

```
I (xx) omnis: kinematics self-check (cases A-D, round trip, null space, side idle): PASS
I (xx) tick: 500 Hz tick running (period 2000 us)
```

and a status line every second beginning like:

```
500.0Hz body NNNus ovr 0 | ...
```

| Field | Must be |
|---|---|
| `500.0Hz` | 500.0 ± 0.1 |
| `ovr` | **0**, sustained — the single most important number in the build |
| `body` | loop body time in µs; must stay well under 2000 |

Also confirm `main_task: Started on CPU1` near the top of the boot log, and no
`Task watchdog got triggered` message, ever.

| Failure | Meaning |
|---|---|
| `Task watchdog got triggered ... IDLE1` | CPU1 idle-watchdog setting did not take — delete `sdkconfig`, rebuild |
| `ovr` steadily non-zero | the loop body is too slow — see Stage 3's I²C note |
| `HALTED: parameter set failed validation` | an edit to `omnis_params.c` broke a range check; the message is repeated every 2 s |

---

## Stage 2 — Kinematics self-check

Nothing to set up — this is the `kinematics self-check ... PASS` line in the Stage 1
boot log. It re-runs the four verified kinematics cases on the ESP32's FPU. A `FAIL`
drops the firmware into a fault loop with the config buzzer pattern.

---

## Stage 3 — IMUs

**Setup:** USB only, battery disconnected. Both GY-521 modules fitted. **Robot
flat and completely still on the bench at power-on** — calibration runs in the
first ~2 s.

### 3.1 Boot

**Pass:**

```
I (xx) mpu6050: 0x68: configured (WHO_AM_I 0x68, +-500 dps, +-4 g, DLPF 94 Hz, 500 Hz, INT open-drain)
I (xx) mpu6050: 0x69: configured (...)
I (xx) imu: IMU A (0x68) ready, mount {+1,+2,+3}
I (xx) imu: IMU B (0x69) ready, mount {-1,-2,+3}
I (xx) imu: gyro calibration 1/5: keep the robot STILL for 2.0 s
I (xx) imu:   IMU A: bias (...) rad/s | gyro sd 0.00NN | |a| 1.00N g sd 0.00NN | NN.N C
I (xx) imu: calibration done
```

A WHO_AM_I warning like `0x70 - not a genuine MPU6050` is **normal** for GY-521
clones (MPU6500 family) and harmless.

During calibration the buzzer ticks softly once a second.

| Failure | Meaning / fix |
|---|---|
| `0x68: no ACK` / `0x69: no ACK` | wiring, power, or AD0 level (A must be GND, B must be 3V3) |
| `read back 0xNN, wrote 0xNN` | a second device is answering, or the bus is marginal — try `OMNIS_I2C_SCL_HZ 100000` |
| `gyro not still` repeated | the robot moved, or vibration (fans, a nearby motor). Calibration retries 5 times, then latches `IMU_CAL` |
| `|a| = 0.NNN g at rest, expected 1.000` | wrong accelerometer range or a failing part |

### 3.2 Attitude signs

Watch the `imu r... p...` fields of the status line:

| Action | Expect |
|---|---|
| Flat and still | `r` and `p` within ±2°, `dis` under 2° |
| Tip **nose down** (OLED end lower) | `p` goes **positive** |
| Tip **left side down** | `r` goes **negative** |
| Tip **right side down** | `r` goes **positive** |

`dis` is the angle between the two IMUs' estimates of "down". It must stay small in
every pose. **Positive pitch = nose down** is intended (it is how the `atan2` model
works) — do not "fix" it.

### 3.3 IMU mounting — if `dis` is large, or before trusting Stage 7

The mounting constants still come from the Rev 1 board photo. On Rev 2.0, confirm
them with the wizard:

1. In `main/omnis_config.h` set `OMNIS_RUN_MOUNT_WIZARD 1`, rebuild, flash, monitor.
2. Follow the prompts: **pose 1** chassis flat and level; **pose 2** front (OLED)
   edge lowered 30–60° and held. Each pose has an 8 s countdown.
3. It prints one `#define OMNIS_IMU_x_MOUNT` line per IMU, marked
   `matches the current header` or `DIFFERS: update the header`.
4. Paste any differing line into `main/omnis_imu_mounting.h` **and**
   `assets/control/omnis_imu_mounting.h` (keep them identical), set the wizard back
   to 0, rebuild, and re-check 3.2.

A large `dis` with correct mounts is a loose module, a bad cable, or a failing
sensor — that is exactly what the `IMU_DISAGREE` fault exists to catch.

### 3.4 I²C timing

The status line's `i2c NNNus` is the worst tick's I²C time. If `ovr` climbs or
`body` approaches 1600 µs, set `OMNIS_IMU_READ_ALTERNATE 1` (one IMU per tick). As a
last resort drop `OMNIS_TICK_RATE_HZ` to 250. Everything uses measured `dt`, so
nothing else needs changing.

---

## Stage 4 — Radio

**Setup:** USB only, battery disconnected. ExpressLRS receiver powered and bound to
the RadioMaster Pocket, radio on.

**Pass:**

```
I (xx) crsf: listening at 420000 baud on GPIO18 (RX-only); will also probe GPIO17
I (xx) crsf: CRSF locked on GPIO18
```

and the status line shows `rc OK LQ100` (link quality under 100 is fine; it varies).

`CRSF locked on GPIO17` means the receiver's Tx is wired to GPIO17. It works — both
pins are inputs — but the harness does not match the schematic.

### 4.1 Channel order and stick polarity

Move one stick at a time and watch `thr pit rol yaw`:

| Stick | Expect |
|---|---|
| Throttle **up** | `thr` → +1 |
| Right stick **forward** | `pit` → +1 |
| Right stick **left** | `rol` → **+1** |
| Left stick (rudder) **left** | `yaw` → **+1** |

- **The wrong field moves** (e.g. throttle moves `rol`): EdgeTX defaults to AETR
  order (ch1 roll, ch2 pitch, ch3 throttle, ch4 yaw). Either reorder the mixer on
  the radio, or change `p->channel_map.*` in `omnis_params.c` (1-based).
- **Right field, wrong sign:** set that stick's `p->rc_scale.invert_*` flag in
  `omnis_params.c`. Never flip a sign anywhere else.
- Centred sticks must read `+0.00` (a ±4% deadzone absorbs small centring error).

### 4.2 Switches

| Switch | Field | Expect |
|---|---|---|
| Arm switch (ch 6) | `arm` | `arm1` only in its **up** position. If up reads `arm0`, set `arm_switch_invert = true` |
| Drive-mode 3-pos (ch 8) | `mode` | `LOW` / `MID` / `HIGH` |
| Speed 3-pos (ch 9) | `spd` | `LOW` / `MID` / `HIGH` |

**The Pocket's throttle stick does not spring-centre.** Arming requires every stick
within 10% of centre, so the throttle must be held at its middle to arm.

### 4.3 Link loss

Switch the radio off. Within 250 ms the line shows `rc LOST` and `faults RC_LINK`,
and the buzzer double-chirps. Radio back on: `rc OK`, the fault clears, chirping
stops. (Before the radio is first seen, the robot is simply silent and cannot arm.)

---

## Stage 5 — Steppers, on the bench pattern

**Setup:** **wheels off the ground.** A4988 current limits set (§0). 12 V connected.
USB connected.

1. In `main/omnis_config.h` set `OMNIS_BENCH_STEP_TEST 1`. Rebuild, flash.
2. The boot log warns `WHEELS WILL TURN ~3 s AFTER BOOT`. The radio is ignored.
3. The pattern cycles, logging each segment:

| Segment | Every wheel should… |
|---|---|
| FORWARD 200 mm/s | **all four roll forward** — the top of each wheel moves toward the OLED end |
| BACKWARD 200 mm/s | all four roll backward |
| STRAFE LEFT | **both left wheels backward; both right wheels forward**, all four at the same speed |
| ROTATE CCW | both left wheels backward, both right forward — but **the front pair spins fast (~3845 Hz) and the rear pair only crawls (~59 Hz)** |
| DIAGONAL vx=vy | FR and RR forward; **FL and RL completely still** |
| ANTI-DIAGONAL vx=−vy | FL and RL forward; **FR and RR completely still** |

> **The rear pair crawling during ROTATE is correct**, not a stuck motor. Under
> the lateral parallel roller layout the rear wheels' yaw lever is 1.5% of the
> front's, so a spin is absorbed almost entirely by the rear rollers. If all
> four wheels spin equally fast, the build is running **stale X-drive
> kinematics** — check that `main/mecanum_kinematics.h` has
> `MECANUM_DELTA_RL == MECANUM_DELTA_FL`.

### 5.1 Fixing directions

Work in this order. Forward motion does not involve roller handedness at all,
so it must be right before any of the other rows mean anything.

- **A wheel runs backward in FORWARD:** flip that wheel's `p->motor.dir_invert[i]`
  in `omnis_params.c` (order `[FL, FR, RL, RR]`). Never fix it in the kinematics.
- **The WRONG SIDE stands still in the two diagonal segments** — right side still
  on `vx=vy`, left side still on `vx=−vy` — and FORWARD was correct: the roller
  handedness is mirrored from what the code assumes. Negate **all four**
  `MECANUM_DELTA_*` constants in `main/mecanum_kinematics.h` together and
  rebuild. Do not touch a `dir_invert` flag for this; see OPERATIONS_GUIDE §4.2.
- **A DIAGONAL pair stands still** (FL+RR or FR+RL) rather than a side: the
  wheels are not in the parallel layout at all, and the derivation does not
  describe this robot.
- **One wheel creeps during a DIAGONAL segment** while its partner is still: a
  DIR flag is wrong — fix FORWARD first.
- The status lines add `step: pulses N underruns 0 submit-fail 0`. **Both counters
  must stay 0.** Non-zero underruns mean the superloop is starving the step queue
  (check `ovr`).
- Optional, with a logic analyser: each STEP pin shows **~3395 Hz** during FORWARD,
  with 10 µs high pulses.

**Set `OMNIS_BENCH_STEP_TEST` back to 0 before going on.** The robot will never arm
while it is 1 — the bench pattern overrides the radio.

Strafe and rotate are only meaningful on the ground (Stage 7.1): on the bench
you can confirm wheel directions, not the resulting motion.

---

## Stage 6 — Arming, disarming, faults

**Setup:** **wheels off the ground**, 12 V, radio on, `OMNIS_BENCH_STEP_TEST 0`.
Mode switch `LOW` (flat), speed `LOW`.

### 6.1 Arming

1. Boot with the arm switch **up**. The robot must **not** arm — a switch left up at
   power-on never arms.
2. Arm switch **down**, then **up**, sticks centred. Buzzer: two short beeps;
   console `ARMED -> ARMED-FLAT`; status `ARMED-FLAT`.
3. Move the sticks: wheels respond, scaled by the speed switch.
4. Arm switch **down**: one long beep, `DISARMED`, wheels stop at once.

### 6.2 Each rejection (three fast beeps + a reason on the console)

| Try | Expected reason |
|---|---|
| Arm with a stick off-centre | `sticks not centred` — then centre it: still not armed until the switch is cycled |
| Arm with the radio off | `no radio link` |
| Mode switch `MID` (balance) while flat | `balance requested but robot not tipped up` |
| Mode `MID`, robot tipped onto a pair, balance gains still 0 | `balance gains are zero` |
| Mode `LOW`, robot tipped 40° | `flat requested but robot is tipped` |

### 6.3 Disarm conditions

| While armed, do | Expect |
|---|---|
| Switch the radio off | wheels stop; `DISARMED`; double chirp. Radio back on with the switch still up: **stays disarmed** until the switch is cycled |
| Lift and tip the robot past 45° | `FAULT raised - active: TILT`; slow half-second beeps; disarmed. Switch down to clear |

### 6.4 Buzzer reference

| Sound | Meaning |
|---|---|
| one short blip | boot OK |
| soft tick every second | calibrating — keep still |
| two short | armed |
| one long | disarmed |
| three fast | arm rejected — reason on the console |
| short then long | balance engaged |
| **continuous** | IMU fault (disagree / comm / init / calibration) — reboot needed |
| double chirp every 0.5 s | radio link lost |
| slow half-second beeps | tilt: fell over or tipped while armed |
| long-short-short | configuration fault (parameters or step generator) |
| triple chirp every second | control loop overrunning |

### 6.5 Fault reference

| Fault | Cleared by |
|---|---|
| `PARAMS`, `IMU_INIT`, `IMU_CAL`, `IMU_COMM`, `IMU_DISAGREE`, `STEP_INIT` | **reboot** — the robot's own sensing or setup cannot be trusted |
| `TILT`, `LOOP_OVERRUN` | disarming with the arm switch down |
| `RC_LINK` | the link returning (re-arming still needs a switch cycle) |

---

## Stage 7 — On the ground, then balancing

### 7.1 Flat driving

**Setup:** open floor, speed `LOW`, mode `LOW`.

Arm and check, gently:

| Input | Robot should |
|---|---|
| throttle forward | drive toward the OLED end |
| right stick left | **strafe** left, without turning |
| rudder left | **rotate** anticlockwise (seen from above) in place |
| right stick diagonal forward-left | move diagonally; **FL and RL** stay still |

- **Strafe goes right when it should go left** (and forward was correct): the
  roller handedness is mirrored from what the code assumes. Negate all four
  `MECANUM_DELTA_*` constants in `main/mecanum_kinematics.h` together and
  rebuild — a four-line change (reference §4, OPERATIONS_GUIDE §4.2). Swapping
  the physical wheels left-to-right is the other valid fix; do not do both.
- **Rotation feels weak or the robot crabs while turning:** expected to a
  degree. Only the front pair contributes meaningfully to yaw under this
  layout, so yaw torque is roughly half an X-drive's. It is a force effect, not
  a kinematics error — the commanded yaw *rate* is still exact.
- **Rotates the wrong way:** a stick polarity (`invert_yaw`) — Stage 4.1.
- Raise to speed `MID`, then `HIGH`, only once `LOW` behaves.

### 7.2 Balance — before anything else

Prerequisites, all of them: Stage 3.3 mounting confirmed, Stage 5 directions
correct, Stage 7.1 driving correct. A tether (a strap to an overhead point, slack
enough to balance, short enough to stop a fall) or a soft surface.

**Balance gains ship at zero, and the robot refuses to arm balance with zero gains.**
No numeric gains are provided — omnis-info.md §13d is right that they depend on mass,
CG height and motor torque, which the firmware does not know.

### 7.3 The sign check — do not skip

1. In `omnis_params.c` set a small `p->balance.kp`, e.g. `100000.0f`
   (units: steps/s² per radian). Leave `ki` and `kd` at 0. Rebuild, flash.
2. Tip the robot up onto its **front pair** (OLED end down) and hold it upright.
3. Mode switch `MID` (or `HIGH` for auto). Arm. Console:
   `ARMED -> ARMED-BAL-SETTLE on the FRONT pair: hold it upright for 400 ms`.
4. After the short-long beep (balance engaged), **gently tip the top of the robot
   toward its top face** (the OLED side).
5. **The wheels must roll the robot toward its top face — under the fall, catching
   it.** If they drive it away from the fall, the controller sign is wrong.
6. Repeat on the **rear pair**.

| Result | Action |
|---|---|
| Both pairs catch the fall | correct — go on to tuning |
| **Both** pairs push the wrong way | set `p->balance.output_invert = true` |
| **Only one** pair is wrong | **stop.** The wheel-sign derivation in `main/balance.h` does not match the hardware (or one pair's DIR flags are wrong). Do not use `output_invert` to hide it |

### 7.4 Tuning

Follow omnis-info.md §13d, on the tether:

1. **kp alone.** Raise until the robot oscillates steadily around upright, then back
   off ~30%.
2. **Add kd** to damp the oscillation. Too much sounds like a buzz from the motors.
3. **Add ki last, small**, only to remove a steady lean.
4. **Trim** (`trim_rad`) for a robot that balances but always drifts one way — a
   CG offset.
5. The outer velocity loop (`vel_bias_gain`) is **off** by design for the MVP. Enable
   it only once the inner loop is solid, starting very small.

**Order of magnitude, not a recommendation:** in the host simulation (a point mass
15 cm above 30 mm wheels) `kp ≈ 5×10⁵` and `kd ≈ 5×10⁴` balanced it. The real robot
will differ.

**Faster kp search with the S1 slider:** set `OMNIS_TUNE_KP_FROM_POT 1` and
`p->balance.tune_kp_max` (e.g. `1000000.0f`). The slider then sets kp live from 0 to
that maximum; while disarmed the status shows `tune: slider 0.NN -> kp NNN`. **Start
with the slider at zero.** Arming balance is allowed whenever `tune_kp_max > 0`
in this mode.

While balancing the per-second status line is **silent** (a blocking log line is a
disturbance). On disarm one summary prints:
`DISARMED after 12.4 s balancing | peak lean 7.3 deg | final speed 120 st/s`.
Set `OMNIS_TELEMETRY_IN_BALANCE 1` to keep the status line while tuning.

### 7.5 Known balance limitations

- **No encoders.** The robot will slowly drift across the room; that is what the
  outer loop is for (omnis-info.md §13a).
- **Reversal dead time.** A wheel reversing waits up to ~8 ms for its queued pulses
  to drain before DIR changes. Balancing in place reverses often; if the robot
  "hunts" near upright, this is a suspect.
- **Mecanum crab.** Turning while balancing (roll stick) drives two mecanum wheels
  differentially, which also produces some sideways force.
- A lean past 35° is treated as a fall (`TILT`).

---

## Status line field guide

```
500.0Hz body 812us ovr 0 | DISARMED | faults none | imu r+0.3 p-1.2 dis 0.4 i2c 640us bad 0 | rc OK LQ100 thr+0.00 pit+0.00 rol+0.00 yaw+0.00 arm0 mode LOW spd LOW | whl +0 +0 +0 +0
```

| Field | Meaning |
|---|---|
| `500.0Hz` | measured loop rate |
| `body` | worst loop-body time this second [µs] |
| `ovr` | missed ticks this second (the line's own cost is excluded) |
| state | `DISARMED`, `ARMED-FLAT`, `ARMED-BAL-SETTLE`, `ARMED-BALANCE` |
| `faults` | active faults, most severe first |
| `imu r p` | fused roll / pitch [°] (flat frame while disarmed) |
| `dis` | worst IMU disagreement this second [°] — fault at 15 |
| `i2c` | worst I²C time in one tick [µs] |
| `bad` | ticks this second without a valid IMU estimate |
| `rc` | `NONE` (never seen), `OK`, `LOST`; `LQ` = uplink link quality % |
| `thr pit rol yaw` | decoded sticks, after the deadzone |
| `arm mode spd` | arm request, drive-mode and speed switches |
| `whl` | commanded wheel rates FL FR RL RR [steps/s] |

## Build-time switches (`main/omnis_config.h`)

| Switch | Default | Purpose |
|---|---|---|
| `OMNIS_TICK_RATE_HZ` | 500 | loop rate |
| `OMNIS_I2C_SCL_HZ` | 400000 | I²C speed |
| `OMNIS_IMU_READ_ALTERNATE` | 0 | one IMU per tick, if I²C is too slow |
| `OMNIS_RUN_MOUNT_WIZARD` | 0 | boot into the IMU mount wizard (Stage 3.3) |
| `OMNIS_BENCH_STEP_TEST` | 0 | bench motion pattern, radio ignored, **wheels off the ground** |
| `OMNIS_TELEMETRY_ENABLED` | 1 | per-second status line |
| `OMNIS_TELEMETRY_IN_BALANCE` | 0 | keep the status line while balancing |
| `OMNIS_TUNE_KP_FROM_POT` | 0 | S1 slider sets balance kp live |

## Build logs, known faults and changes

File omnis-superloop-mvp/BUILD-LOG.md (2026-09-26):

# OMNIS Superloop MVP — Build Log

A running history of this build: what was made, why it was made that way, what
was learned, and what is still open. Appended after every stage — read
top-to-bottom it should explain how the thing came to be, not just what it
currently is.

Newest entries at the bottom.

---

## 2026-09-05 — Planning

**Built:** `PLAN.md`. No code.

> **2026-09-16:** `PLAN.md` was folded into this file once the build was complete
> and deleted. Its decisions (1a, 1b, 1c) are recorded below under their original
> numbers, and its completion tables are in the final entry. Source comments that
> cited `PLAN.md §1a` now cite this entry.

**Decisions:**

**1a — What "no FreeRTOS" actually means here.** ESP-IDF *is* FreeRTOS; `app_main`
is a task and every IDF driver uses RTOS primitives internally. There is no way
to reach zero FreeRTOS short of writing bare-metal register drivers for every
peripheral, which the deadline does not allow. The rule adopted instead: **no RTOS
primitive appears in OMNIS-authored code** — no `xTaskCreate`, queues,
semaphores, mutexes, or `vTaskDelay`. IDF driver internals are treated as part of
the hardware.

Arduino IDE was offered as an alternative and rejected **on evidence**:

- It does not remove FreeRTOS. `loop()` *is* a FreeRTOS task — the installed core
  3.3.10's own `cores/esp32/main.cpp:113` calls
  `xTaskCreateUniversal(loopTask, ...)`. Arduino moves the `xTaskCreate` out of
  your code and into the core where you cannot see or control it. That is
  strictly *less* control over the exact thing the rule is about.
- It breaks decision 1b. Arduino's RMT wrapper has no transaction queue; its own
  `esp32-hal-rmt.h` states a second `rmtWriteAsync()` issued mid-transfer returns
  `false`. Only `rmtWriteLooping()` (Option A) is reachable there.
- The IDF toolchain was already installed and documented, so Arduino's usual
  setup-speed advantage did not apply.

Both toolchains give an identical "no RTOS in my code" guarantee, so nothing was
traded away by staying with ESP-IDF v6.0.2.

**1b — RMT strategy: Option B, burst re-arm.** Each tick, queue a short pulse
block at the current period with `queue_nonblocking`. Rejected Option A (infinite
loop) because changing rate requires `rmt_disable()`/`enable()`/`transmit()` on
four channels at up to 500 Hz, with a glitch on every rate change.

**1c — Balance scope:** inner 500 Hz lean-angle PID in; §13b's outer
velocity-bias loop and live side-detection out of the MVP.

**Learned:** ESP32-S3 has **exactly 4 RMT TX channels**
(`RMT_LL_TX_CANDIDATES_PER_INST = 4`) — precisely enough for four steppers, zero
spare. Verified against the installed IDF, not assumed.

**Open:** questions 5 and 6 (CRSF kill-switch channel; RC scaling constants)
carry stated defaults to be confirmed on the bench at the stage that uses them.

---

## 2026-09-05 — Stage 1: skeleton, pin map, params, 500 Hz tick

**Built:**

| File | What it does |
|---|---|
| `CMakeLists.txt`, `main/CMakeLists.txt` | Standalone IDF project, `MINIMAL_BUILD ON` |
| `sdkconfig.defaults` | The watchdog/affinity settings that make a superloop legal |
| `main/omnis_pins.h` | Every GPIO from omnis-info.md §3a, plus reserved pins |
| `main/omnis_params.h/.c` | `params.json` §9f schema as a struct, compile-time defaults |
| `main/tick.h/.c` | 500 Hz GPTimer, ISR sets a flag, overrun counter |
| `main/main.c` | Safe GPIO state, then the superloop with self-measurement |

**Result:** builds clean, zero warnings. 154 KB binary, 85% of the app partition
free.

### Design decisions and why

**The superloop needs two sdkconfig settings to be legal.** A `while(1)` that
never yields starves its core's idle task and the task watchdog trips within
seconds. Fix: pin `app_main` to CPU1 (`ESP_MAIN_TASK_AFFINITY_CPU1`) and stop
watchdogging CPU1's idle task (`ESP_TASK_WDT_CHECK_IDLE_TASK_CPU1=n`). CPU0 keeps
its idle watchdog and runs the system's housekeeping. The **interrupt** watchdog
is deliberately left on — it catches a hung ISR, which is a bug worth hearing
about.

**The flag is a plain `volatile bool`, and that is sufficient rather than
merely expedient.** `app_main` is pinned to CPU1 and the GPTimer interrupt is
allocated on whichever core registers it — CPU1, since `tick_init()` runs from
`app_main`. Producer and consumer are the same core, so there is no cross-core
visibility problem and no barrier is needed. **If `app_main` is ever un-pinned,
this reasoning breaks and the flag must become atomic.** Recorded here because it
is exactly the kind of assumption that silently rots.

**Overruns drop the tick rather than catching up.** When the ISR fires with the
previous tick still pending, it counts an overrun and moves on. Trying to catch
up would make `dt` wrong in the EKF, which is worse than a skipped cycle.

**Hardware auto-reload, not ISR-rewritten alarms.** The period is maintained by
the timer peripheral, so a late ISR delivers a late tick rather than accumulating
drift.

**`gpio_set_level()` is called *before* `gpio_config()` for COM_ENA.** Looks
backwards, is deliberate: it primes the output latch so the pin drives the
disabled level the instant it becomes an output, instead of briefly driving
whatever was in the register. §7g point 5 wants the kill line to be one of the
earliest things that works, and this is the earliest it can possibly be.

**The status report sits outside its own measurement window.** A log line takes
far longer than one 2 ms tick, so counting it would guarantee an overrun every
second and drown the real signal. Stats reset after printing. This report is
scaffolding and goes away once the loop has real work.

**Headroom is reported as well as overruns.** `tick_wait()` returns the
microseconds it spent waiting. Overruns are a *lagging* indicator — by the time
one appears the loop is already too slow. Headroom trending toward zero is the
*leading* indicator.

### Learned

- **`CONFIG_ESP_CONSOLE_UART_BAUDRATE` is silently ignored unless
  `CONFIG_ESP_CONSOLE_UART_CUSTOM=y`.** The first attempt set the baud and it
  stayed at 115200 with no warning. Caught by checking the generated `sdkconfig`
  rather than trusting `sdkconfig.defaults`. **Worth doing for every option
  added** — a wrong or unprompted Kconfig name fails silently.
- Settled on **460800**, not 921600, because esptool already flashes this board
  at 460800 — evidence the bridge handles that rate. At 115200 a ~130-character
  log line occupies ~11 ms, five whole ticks.
- The v6.0.2 environment will not activate via `export.sh` on this machine: it
  looks for a py3.11 venv while the install is py3.14. Use
  `. ~/.espressif/tools/activate_idf_v6.0.2.sh` instead. This matches the warning
  already in `phase0-toolchain-environment.md` §7.

### Known limitations

- **The 500 Hz figure is not yet hardware-verified.** It builds and the logic is
  right, but nothing has run on the board. The Stage 1 test is what confirms it.
- `max_accel_steps_s2 = 20000` is a placeholder. It is the §13c lost-step
  defence, and the correct value depends on the A4988 Vref current limit that has
  not been set yet (§3f).
- RC scaling constants (`vx_max_mmps` etc.) are derived from Case D's practical
  ceiling but unverified on hardware — planning question 6.
- `PIN_TICK_HEARTBEAT` (GPIO35) is bring-up scaffolding and should be removed
  once the tick is trusted.

### Still to do

Stages 2–7: kinematics port + host tests, MPU6050 driver + EKF, CRSF parser, RMT
step generation, fault/buzzer, superloop integration.

---

## 2026-09-07 — Stage 1 bench test: PASSED

First hardware run. Flashed to the EdgeHax S3 Pro over `/dev/cu.usbmodem101`,
USB cable only, battery disconnected.

### Result

```
I (0)     main_task: Started on CPU1
I (10)    omnis: COM_ENA driven DISABLED (GPIO1 = 1) - motors are off
I (10)    omnis:   yaw lever arm k = 226.5 mm, k/r = 7.550  (expect 226.5, 7.550)
I (10)    tick:  500 Hz tick running (period 2000 us)
I (2010)  omnis: 500.16 Hz | period 2000-2000 us | headroom min 1998 us | overruns 0 | uptime 2 s
I (10010) omnis: 500.13 Hz | period 2000-2000 us | headroom min 1998 us | overruns 0 | uptime 10 s
```

| Criterion | Target | Measured | |
|---|---|---|---|
| Overruns | 0, sustained | **0** across all 10 windows | pass |
| Period jitter | ±5 us | **2000–2000 us**, no measurable jitter | pass |
| Geometry | k=226.5, k/r=7.550 | exact | pass |
| COM_ENA at boot | disabled | `GPIO1 = 1`, before anything else | pass |

Two settings confirmed working that could only be confirmed on hardware:

- `main_task: Started on CPU1` — the `ESP_MAIN_TASK_AFFINITY_CPU1` pinning took
  effect. This is the premise the plain-`volatile` flag argument rests on.
- No task-watchdog trip over 10 s of a never-yielding loop — the CPU1 idle-WDT
  setting took effect.

**Headroom: 1998 us of 2000.** The Stage 1 loop body costs ~2 us, so 99.9% of the
tick budget is still free for Stages 2–7. The console prints at GPIO43/44 as
expected (`cpu_start: GPIO 44 and 43 are used as console UART I/O pins`).

### Bug found and fixed: the reported rate was biased high

The rate read a consistent **500.13 Hz** rather than 500.00, while `period`
measured an exact `2000-2000 us`. The period is measured independently and is
ground truth, so the discrepancy had to be in the reporting arithmetic — and it
was. Two compounding off-by-ones in `main.c`:

1. `window_start` was set immediately *after* the status print, which is
   mid-period, not on a tick edge.
2. The window counted N ticks but divided by the elapsed time of **N-1**
   intervals plus a partial one.

Arithmetic confirms it exactly: a first-tick offset of 1740 us gives
`500 x 1e6 / (1740 + 499x2000) = 500.13 Hz`, the precise figure observed.

Fixed by anchoring `window_start` on the first tick edge of each window and
dividing by `window_ticks - 1`, since N tick edges span N-1 intervals.

**Why fix a cosmetic diagnostic:** this same reporting block is how loop health
gets judged in every later stage. A rate that reads systematically high hides
exactly the degradation it exists to reveal — and when a real slowdown appears in
Stage 3 or 5, nobody wants to be re-deriving whether the number is trustworthy.

**The hardware was never wrong.** No timing behaviour changed; only the number
printed about it.

### Still to do

Stages 2–7, unchanged. Stage 1's `PIN_TICK_HEARTBEAT` scaffolding on GPIO35
remains and should be removed once the tick is no longer under suspicion.

---

## 2026-09-07 — Stage 2: kinematics port, RC mapping, drive pipeline

**Built:**

| File | What it does |
|---|---|
| `main/mecanum_kinematics.{c,h}` | **Byte-identical copy** of `assets/kinematics/`. Not re-derived, not edited. |
| `main/drive.{c,h}` | RC sticks -> body velocity, and the full pipeline in the required order |
| `test/test_kinematics.c` | 76 host assertions against the reference's verified numbers |
| `test/run_host_tests.sh` | `cc` + run. No ESP-IDF, no hardware. |

Also added stick-polarity inverts to `omnis_rc_scale_t`, because the reference is
emphatic that a reversed transmitter axis is corrected at the mapping layer and
nowhere else.

**Result:** 76 host assertions pass, 0 fail. Firmware builds clean, zero
warnings, 161 KB (85% of the partition still free).

### Design decisions and why

**The port is byte-identical, verified by `diff`.** The whole value of that
module is that its numbers are checked; "porting" it by retyping would throw that
away. `diff -q` against the asset is part of the stage's verification.

**The pipeline order is encoded once, in `drive_solve()`, not trusted to call
sites.** Reference §6 has two ordering rules that are easy to get wrong and
silent when you do:

- *Clamp before computing FK.* Feeding pre-clamp rates to forward kinematics is
  the classic open-loop drift bug — the estimator believes a velocity the
  hardware never produced.
- *Clamp with a common scale factor, never per-wheel.* Per-wheel clipping warps
  the motion vector; a commanded strafe becomes an arc.

**The null-space health metric is taken post-clamp but PRE-deadband.** This was
the one genuinely non-obvious ordering call. `mecanum_clamp()` scales all four
wheels equally so it preserves the null space, but `mecanum_deadband()` is
deliberately a *per-wheel* operation and therefore legitimately injects
null-space energy. Measuring after it would make the metric fire on healthy
commands — and an alarm that cries wolf gets ignored, which is worse than not
having it.

**Forward kinematics is taken AFTER the deadband**, for the mirror-image reason:
a deadbanded wheel genuinely will not turn, so the commanded-velocity estimate
must reflect that.

**`vx` is deliberately NOT clamped in `drive_rc_to_body()`.** Throttle and pitch
are additive into `vx`, so full deflection on both gives 450 mm/s against a
300 mm/s nominal. Reference §5 says handle this *either* by clamping combined
`vx` *or* by relying on the wheel clamp — "but not both, or the response becomes
non-linear near full stick." Chose the wheel clamp: clamping `vx` alone while
leaving `vy` and `w` untouched would rotate the commanded motion vector, so a
full-throttle diagonal would quietly become a *different* diagonal. The common
factor scales all three components together, so direction survives and only
magnitude drops.

**A NaN stick reads as centred.** `clamp_unit()` fails both comparisons on NaN,
so it is caught explicitly. Without that, one NaN channel propagates through the
IK into a step rate. A dead stick reading as centred is the safe interpretation.

**Boot-time self-check on the target.** The same four cases run on the Xtensa FPU
at startup, and the firmware refuses to enter the superloop if they fail.
IEEE-754 says float32 must agree bit-for-bit with the Mac, but "must" and "does"
are different claims and this costs microseconds to settle. A silent divergence
would otherwise surface as a robot that drives subtly wrong.

### Verified numbers

All four reference cases reproduce exactly:

| Case | Input | FL | FR | RL | RR |
|---|---|---|---|---|---|
| A | `vx=200` | +3395.305 | +3395.305 | +3395.305 | +3395.305 |
| B | `vy=200` | −3395.305 | +3395.305 | +3395.305 | −3395.305 |
| C | `w=1.0` | −3845.183 | +3845.183 | −3845.183 | +3845.183 |
| D | `vx=200 vy=100 w=0.5` | −224.939 | +7015.550 | +3170.366 | +3620.244 |

Case D round-trips through FK to `(200.0, 100.0, 0.5)`; null space `-0.0002`
(float32 noise). Reference §4's bench test holds: a `vx = vy` diagonal leaves FL
and RR **exactly** `0.0f`, not merely small.

### Known limitations

- The per-tick stick input is **synthetic** — a slow circle in (vx, vy) with some
  yaw, so all four wheels vary and both the clamp and deadband get exercised.
  The CRSF parser replaces it in Stage 4.
- Nothing drives a motor yet. `sol.rates` is computed and measured but discarded;
  Stage 5's RMT generator is what consumes it.
- Stick polarity inverts all default to `false` — unverified until a radio is
  bound in Stage 4 (planning question 6 territory).
- `vx_max_mmps` and friends remain derived-but-unverified.

### Still to do

Stages 3–7: MPU6050 + EKF, CRSF parser, RMT step generation, fault/buzzer,
integration.

---

## 2026-09-15 — Board Rev 2.0 pinout migration

**Context:** the builder supplied the Rev 2.0 schematic and asked for every
remaining stage to be finished in one pass (Claude access lapses for ~2 months
from 2026-09-16; the board is not yet assembled). Per-stage approval is replaced
by per-stage commits, target builds with zero warnings, host tests, and
`TESTING.md` for the bench. Recorded in the planning entry above.

**Built:** `main/omnis_pins.h` rewritten; `main/main.c` loses COM_ENA and the
GPIO35 heartbeat; `sdkconfig.defaults` flash header 16 MB -> 8 MB; master
`assets/documentation/omnis-info.md` §2/§3/§7/§8/§9 updated.

### How the pinout was verified

Three sources existed and they did not all agree:

1. The rendered schematic image the builder attached.
2. `assets/pcb/OMNIS.kicad_sch`.
3. `assets/pcb/rev2-pin-assignment.md`, a planning document.

Rather than read pin numbers off a picture, every ESP32 pin was traced through
the KiCad file's wire segments to its global label (symbol at 231.14,125.73; lib
pin offsets applied; BFS over wire endpoints). **The image and the schematic
agree on all 36 GPIOs.** The planning doc disagrees on seven nets — FR_STEP,
FR_DIR, BL_DIR and four buttons. The schematic is authoritative and is what
`omnis_pins.h` encodes; the full table is in that header and in master
omnis-info.md §3i.

The same trace also settled a scare from the rendered image: the `MPU2_INT`
junction appears to touch the `I2C_SDA` label. It does not. R3, `MPU1_INT` and
`MPU2_INT` join onto GPIO7 only; `I2C_SDA`/`I2C_SCL` sit directly on the GPIO8/9
pin ends with no wire to the interrupt net.

### What Rev 2.0 changes in behaviour

**COM_ENA is gone.** All four A4988 EN# pins are hardwired to GND. Consequences,
all now reflected in code and docs:

- The drivers are energised whenever 12 V is present — including before firmware
  runs. `gpio_safe_state()` now pins the STEP lines low first, because a floating
  STEP input on a live driver can move a wheel.
- The failsafe is no longer "disable the drivers". It is **"stop generating STEP
  pulses"**. The motors hold position; they do not go limp. Only unplugging the
  battery de-energises them.
- `PIN_STEPPER_EN` survives as `GPIO_NUM_NC`, so restoring the enable later (the
  plan's cuttable-link hedge onto GPIO0/3/45) is a one-line change.

**Shared IMU interrupt.** Both MPU6050 INT pins sit on GPIO7 with a 10 k
pull-up. That is only safe with both chips open-drain (`INT_PIN_CFG` = 0xC0),
which Stage 3 configures at boot.

**Current revised-board mapping encoded in `omnis_pins.h`:** FR_STEP on GPIO1 and
BR_DIR on GPIO2; the earlier GPIO40/GPIO42 labels were superseded by the physical
PCB reroute. RL_DIR remains on
strapping pin GPIO46, and GPIO38–42 depending on GPIO3 staying NC.

### Decisions

**The Stage 1 heartbeat on GPIO35 was a bug, and is removed rather than moved.**
GPIO35 is an octal-PSRAM line on the N16R8. It happened to work because PSRAM is
not enabled in this build, but toggling a PSRAM data line at 250 Hz is not
something to keep. The tick is verified, so the heartbeat has no remaining job.

**Flash header 8 MB.** The Rev 2.0 schematic symbol is
`ESP32-S3-DEVKITC-1U-N8R2` (8 MB); the board docs say N16R8 (16 MB). An 8 MB
header boots on both; a 16 MB header on a real 8 MB part is the one combination
that can misplace partitions. The app is ~0.2 MB, so nothing is lost.

### Found while reading ahead — fixed in the next commit

Two latent bugs in `assets/control/`, found before porting it, both of which
would have bitten in Stage 3 or 7:

1. **`pid_t` collides with POSIX.** `typedef struct {...} pid_t;` in
   `assets/control/pid.h` conflicts with `sys/types.h`, which IDF headers pull in.
   Confirmed on both xtensa-esp32s3-elf-gcc and host clang. The host test only
   passed because nothing it included happened to reach `sys/types.h`.
2. **The flat-frame pitch folds at the balance point.** Balance mode sits at
   pitch ≈ ±90°, where `atan2(-ax, hypot(ay,az))` reads 85° for both 85° and 95°
   of nose-down. The lean direction is lost exactly where it matters.
   `attitude-ekf-derivation.md` §7 called this "survivable" — that was wrong.

---

## 2026-09-15 — Two latent bugs fixed in `assets/control/` before porting

Both found by reading ahead to Stages 3 and 7, before any of the code reached
the target. Fixed at the source so the asset folder and the firmware stay
byte-identical.

### 1. `pid_t` collides with POSIX

`assets/control/pid.h` declared `typedef struct {...} pid_t;`. `pid_t` is the
POSIX process-id type in `sys/types.h`, which ESP-IDF headers include throughout.
Reproduced on both compilers the moment `sys/types.h` is in scope:

```
xtensa-esp32s3-elf-gcc: error: conflicting types for 'pid_t'; have 'struct <anonymous>'
host clang:             error: typedef redefinition with different types
```

The host test had passed only because nothing it included happened to reach
`sys/types.h`. Renamed to **`pid_ctrl_t`** everywhere (header, source, test, PID
diagram). Verified: `pid.c`, `attitude_ekf.c` and `imu_fusion.c` all compile on
xtensa with `-include sys/types.h -include unistd.h -Werror`.

(First rename attempt silently did nothing: macOS `sed -E` does not support `\b`.
Caught by the zero match count; redone with `perl`.)

### 2. The flat-frame pitch folds at the balance point

This one is a design error in my own earlier documentation, not a typo.

`pitch = atan2(-ax, hypot(ay, az))` is confined to ±90° because the hypot is
never negative. Balance mode sits at ±90° — the edge of the range — where the
formula **reflects**:

| Nose-down | `pitch` reads |
|---|---|
| 85° (leaning 5° back from upright on the front pair) | **84.999992°** |
| 95° (leaning 5° forward) | **84.999985°** |

Which way the robot is falling — the only thing a balancer needs — is destroyed
at the operating point. `attitude-ekf-derivation.md` §7 was titled "why it is
survivable" and argued pitch passes cleanly through 90°. That was wrong, and a
balance controller built on it would have pushed the wrong way on one side of
upright. The EKF would also have fought itself: past the fold, the gyro
prediction and the accelerometer update disagree in sign.

**Fix: change frames, not formulas.** While balancing, the body-frame accel and
gyro are rotated a further 90° about Y before reaching the EKF, so the pose looks
level to the filter. Both frames put `+X'` on the chassis top face:

| Pose | Map | Verified: 95°/85° read |
|---|---|---|
| Front pair down | `{+3,+2,−1}` | **+5.000° / −5.000°** |
| Rear pair down | `{+3,−2,+1}` | **+5.000° / −5.000°** |

So positive balance-frame pitch always means "falling forward", in either pose,
and `gyro_y'` is always its rate (checked: `+0.1` rad/s for a forward fall on
both pairs). An EKF seeded at +3° followed the lean through zero to
**−3.004°**. The flat-frame pitch keeps its *sign* through the fold, so it still
picks the grounded pair at arming — which is all it is used for now.

Constants `OMNIS_IMU_BALANCE_FRAME_FRONT_DOWN` / `_REAR_DOWN` added to
`omnis_imu_mounting.h`; the mounting self-check now covers all four descriptors.
Corrected: derivation §7 (rewritten, with a correction notice), reference §7
items 2–3, sensor-fusion reference (the disagreement metric is
rotation-invariant, so needs no change), README ("four things that will bite"),
the walkthrough's integration example, and master omnis-info.md §11c.

**Host tests:** `assets/control` 76 → **97** assertions (Case 13 added), 0 fail.

---

## 2026-09-15 — Stage 3: MPU6050 driver, IMU orchestration, EKF + fusion ported

**Built:**

| File | What it does |
|---|---|
| `main/mpu6050_regs.h` | Register map, config values, pure 14-byte burst decoder (host-tested) |
| `main/mpu6050.{c,h}` | I2C transport on the v6 `i2c_master` API; health counters |
| `main/imu.{c,h}` | Both IMUs: bus bring-up, boot calibration, per-tick fusion, frame switching, mount wizard |
| `main/omnis_time.h` | Busy-wait delay for boot only — no `vTaskDelay` exists in this build |
| `main/omnis_config.h` | Build-time switches: tick rate, I2C speed, alternate reads, mount wizard |
| `main/{attitude_ekf,imu_fusion,pid}.{c,h}`, `omnis_imu_mounting.h` | **Byte-identical** to `assets/control/` (checked with `cmp`) |
| `test/test_mpu6050.c` | 28 assertions: decoding, sign extension, full scale, plausibility, identity |
| `test/test_control.c` | The asset suite, 97 assertions, now run against the firmware copies |
| `test/run_host_tests.sh` | Rewritten to run every suite and fail if any one fails |

**Result:** target build clean, zero warnings, 189 KB (82% of the partition
free). Host tests: **3 suites, 201 assertions, 0 failures.** No hardware yet — the
board is not assembled.

### Design decisions and why

**`INT_PIN_CFG` is the first register written after reset.** Board Rev 2.0 ties
both INT pins to GPIO7. The part powers up push-pull; making it open-drain before
anything else shortens the window in which two push-pull outputs share a wire. The
window is benign anyway (interrupt disabled, both idle at the same level), but
there is no reason to hold it open. The interrupt stays disabled; the tick polls.

**Every configuration write is read back.** Catches a failed write, a wrong
address, and a second device answering in place of the intended one — all of which
otherwise produce an IMU that "works" with the wrong full-scale range, i.e. angles
that are wrong by a factor.

**MPU6500-family parts are accepted.** GY-521 boards very often carry an MPU6500
(WHO_AM_I 0x70) instead of a genuine MPU6050 (0x68). Every register used here has
the same address and meaning, so rejecting them would reject most parts actually
sold. Logged as a warning. Only the temperature formula differs, and temperature is
diagnostic.

**A dead IMU is detected from I2C behaviour, not the interrupt.** With a shared
INT line the pin cannot say which IMU fired. So `mpu6050_read()` counts
consecutive errors *and* consecutive byte-identical bursts: a live sensor's noise
floor changes the 14 bytes every sample, so 50 identical bursts (100 ms) is a
latched part. Implausible bursts (all 0x00 or all 0xFF) are rejected outright —
gravity makes an all-zero accelerometer impossible.

**Data path order is fixed:** decode → sensor mount → subtract bias → balance
frame (only while balancing) → EKF. The mount must precede the EKF or the
antiparallel IMUs read 20° apart. Bias is subtracted in the body frame, so a later
frame change never has to rotate a bias state — `imu_set_frame()` just re-seeds
the filters from the last accelerometer sample.

**Measured dt, not the nominal period.** Correct after an overrun, correct when a
read fails for a few ticks (the next good read integrates across the gap), and
correct when `OMNIS_IMU_READ_ALTERNATE` halves each IMU's rate. Clamped to 50 ms so
a long stall cannot integrate a wild angle in one step.

**Calibration gates on stillness, and fails rather than guessing.** 2 s of
samples per attempt, up to 5 attempts. Rejected if gyro std-dev exceeds 0.02 rad/s
(~20× the noise floor), if |a| std-dev exceeds 0.02 g, or if mean |a| is not within
0.1 g of 1 g — that last one is not a motion problem but a wrong full-scale setting
or failing part. A bias measured while someone was holding the robot would bake a
drift into every later angle.

**Mount wizard instead of arrow-reading.** `OMNIS_RUN_MOUNT_WIZARD 1` boots into a
timed two-pose procedure that runs `imu_mount_resolve()` on raw sensor data and
prints `#define` lines to paste, flagging any that differ from the header. It
matters more on Rev 2.0: the IMU placement is not confirmed on the new board.

**Escape hatch for I2C cost.** Two 1+14-byte transactions at 400 kHz are
estimated at a few hundred µs plus driver overhead, but the v6 `i2c_master` driver's
real per-transaction cost is unmeasured. `OMNIS_IMU_READ_ALTERNATE` reads one IMU
per tick, halving it, with no other change needed because every consumer uses
measured dt.

### Known limitations

- **I2C time on the real bus is unmeasured.** The status line reports the worst
  tick (`i2c NNN us`) so the first bench run settles it.
- **Stage 3 halts on IMU init or calibration failure.** Stage 6 turns both into
  latched faults that block arming while the radio and buzzer keep working.
- The drive pipeline still runs on synthetic sticks; nothing drives a motor yet.
- The IMU mounting constants are still those confirmed on the Rev 1 board photo.
  Rev 2.0 placement must be confirmed with the wizard.

---

## 2026-09-15 — Stage 4: CRSF parser, RC input decoding, UART glue

**Built:**

| File | What it does |
|---|---|
| `main/crsf_parser.{c,h}` | Pure byte-stream parser: framing, CRC-8/DVB-S2, 11-bit unpack, link stats |
| `main/rc_input.{c,h}` | Pure: channels -> sticks, arm request, drive mode, speed, pot |
| `main/crsf.{c,h}` | UART1 RX-only, zero-timeout polling, RX-pin auto-detect, link-loss logic |
| `test/test_crsf.c` + `test/crsf_golden.h` | 55 assertions; golden frames from an independent implementation |
| `main/omnis_params.*` | Channel map gains drive mode / speed / pot / arm invert; `rc` and `control` blocks |
| `main/main.c` | Radio started before IMU calibration and polled during it; synthetic sticks replaced |

**Result:** target build clean, zero warnings, 213 KB (80% free). Host tests:
**4 suites, 256 assertions, 0 failures.**

### Design decisions and why

**Golden frames come from a separate implementation.** `crsf_golden.h` is
generated by a Python implementation of the packing and CRC written independently
of the C, and the C must reproduce its bytes exactly. A test that compares a
function with itself proves nothing; two independent implementations agreeing on
a bug is far less likely. The all-centre frame it produced,
`c8 18 16 e0 03 1f … 7c ad`, is the canonical CRSF centre frame widely published
for ExpressLRS — a third, external confirmation. The CRC also passes the published
CRC-8/DVB-S2 check value (`"123456789"` → `0xBC`).

**RX-only UART, and that is what makes pin auto-detect safe.** The MVP sends no
telemetry, so the UART TX signal is never routed to a pin. If no valid frame
arrives on GPIO18 within 1.5 s, the receive signal moves to GPIO17 and back until
frames appear. Both pins are inputs the whole time, so a crossed harness can never
put the ESP32's output against the receiver's. Rev 1.0's receiver-perspective net
names are exactly the mistake this rescues.

**Resync drops one byte, never a buffer.** A truncated frame's header claims bytes
that are actually the start of the next, perfectly good frame. Discarding the
buffer on the CRC failure would throw that frame away and cost a whole frame
interval every time the line glitches. Tested explicitly: a 10-byte truncated
frame followed by a good one recovers the good one.

**Link loss produces a NEUTRAL command, never a held one.** §7f: holding the last
value on link loss is wrong for a robot. The link is OK only while RC frames arrive
within 250 ms; otherwise `rc_command_neutral()` — centred sticks, no arm request.
An optional uplink-LQ floor exists but defaults off: the frame timeout is the
primary detector, and a floor set too high disarms on a fringe link for no benefit.

**The arm switch needs a decisive position.** HIGH (> +0.5) arms, LOW or MID
never does, whichever way `arm_switch_invert` is set. A 3-position switch mapped to
the arm channel by mistake therefore cannot arm the robot from its centre detent.

**Rescaled deadzone.** Inside ±4% the stick reads exactly 0; outside it ramps
from 0, so there is no step when the stick leaves the band — a plain "zero it if
small" deadzone makes the robot lurch at the edge.

**Arming will require every stick within 10% of centre** (enforced in Stage 6).
The Pocket's throttle stick does not spring-centre, and this mapping puts
throttle-centre at zero speed: a throttle left at the bottom is full reverse. The
tolerance is what stops the robot arming straight into it.

**Bounded, non-blocking polling.** At most 4 × 128 bytes are parsed per tick with
`uart_read_bytes(..., 0)`; the 1 KB ring buffer holds ~40 frames, so even a long
stall cannot overflow it. `uart_set_rx_timeout(3)` hands bytes over after three
idle symbols, so a frame reaches the parser well inside one tick.

**The radio starts before IMU calibration**, and is polled from the calibration
loop's per-tick hook, so it has found its pin and locked by the time the robot is
ready.

### Known limitations and things to check on the bench

- **Channel order.** EdgeTX defaults a new model to AETR (ch1 roll, ch2 pitch, ch3
  throttle, ch4 yaw); §9f's map is throttle-first. Either reorder the mixer on the
  radio or change the four numbers in `omnis_params.c`. The status line prints
  throttle/roll/yaw so the check takes a minute.
- **Stick polarity** is still unverified; `invert_*` flags are all false.
- No telemetry is sent back to the radio (battery sensing is out of scope anyway).
- Until the radio is powered, the RX pin probe keeps swapping every 1.5 s. Harmless —
  both pins are inputs — and it stops at the first valid frame.
- Nothing drives a motor yet: `sol.rates` is computed from real sticks and discarded
  until Stage 5.

---

## 2026-09-15 — Stage 5: RMT step generation, acceleration limit, bench pattern

**Built:**

| File | What it does |
|---|---|
| `main/step_wave.{c,h}` | Pure STEP waveform generator: rate in, RMT-style symbols out |
| `main/step_gen.{c,h}` | Four RMT TX channels, burst re-arm, exact queue regulation, DIR state machine |
| `main/drive.{c,h}` | + `drive_slew_rates()`: acceleration limit by a common factor |
| `main/omnis_params.*` | `motor` block: per-wheel DIR invert, pulse width, minimum low time |
| `main/omnis_config.h` | `OMNIS_BENCH_STEP_TEST` — fixed motion pattern, no radio, wheels off the ground |
| `main/main.c` | Step generation initialised straight after parameters; bench-gated drive path |
| `sdkconfig.defaults` | RMT done-callback and copy encoder in IRAM |
| `test/test_step_wave.c` | 87 assertions on the reconstructed waveform |
| `test/test_kinematics.c` | + 13 slew-limiter assertions (89 total) |

**Result:** normal build clean, zero warnings, 236 KB; bench variant
(`OMNIS_BENCH_STEP_TEST 1`) also clean, 240 KB. Every sdkconfig option confirmed
in the regenerated file. Host tests: **5 suites, 356 assertions, 0 failures.**
In a normal build the motors still never step — the supervisor that arms them is
Stage 6/7.

### Design decisions and why

**Chunks, queued with EXACT regulation.** Each tick, each wheel keeps three
~2 ms bursts queued. "Pending" is not estimated from timing: it is `submitted`
(superloop) minus `completed` (incremented in the RMT done-callback, the module's
only ISR). So the generator can never over-fill the driver's queue, and a late
tick is absorbed by the ~6 ms lead and topped up on the next one.

**Payload buffers outlive their transactions.** `rmt_transmit()` does not copy:
the copy encoder reads the buffer from the ISR while it plays. Each wheel owns a
ring of 8 buffers against a queue depth of 6, so a slot is never rewritten while
queued. A failed submit does not advance the ring or commit the waveform phase —
that chunk is simply regenerated next tick. One encoder per channel, because an
encoder holds per-transaction state.

**Stopping overwrites queued payloads instead of calling `rmt_disable()`.** Read
from the installed IDF's `rmt_tx.c`: `rmt_tx_disable()` recycles only the
transaction in progress, without a done callback, and leaves everything else
queued to play after the next enable — steps after a stop, plus a pending count
that never drains. Instead `step_gen_stop()` clears the level bits of every queued
burst in place. The ISR only ever reads those words, so the rewrite is race-free;
queued bursts play as silence and the counters stay consistent. At most the burst
already copied into RMT memory — one tick — still plays.

**Direction reversal drains before touching DIR.** Queued bursts were generated
for the old direction; flipping DIR while they play sends those steps the wrong
way. A reversal stops queueing, waits for the queue to empty, writes DIR, holds a
full tick (2 ms against the A4988's 200 ns setup), then resumes.

**Waveform guarantees, each tested on a reconstructed timeline across chunk
boundaries:** a pulse is never split and every chunk ends LOW (the output idles
low between transactions, so a split pulse becomes two steps and a high-ended
chunk can merge two into one); every pulse is exactly 10 µs and every gap at least
10 µs, including through 20 s of random rate changes; no zero-duration halves
(RMT reads zero as end-of-transmission).

**The rounding residue is carried.** Edges land on whole microseconds, but the
error is fed back into the phase. Verified over 10 s at 3395.305 steps/s (Case A):
within 1.5 pulses of exact. Rounding each edge independently would have lost ~55
steps.

**Phase is a fraction of the period.** Speeding up from a crawl does not wait out
the old period: after one chunk at 20 steps/s, the first pulse at 7000 steps/s
came at **137 µs**, not ~48 ms later.

**Acceleration is limited by a common factor.** Slewing each wheel separately
lets small changes arrive before large ones, warping the motion vector mid-change
exactly as per-wheel clipping does. With one factor, every intermediate command
lies on the straight line between old and new motion. Verified: mid-transition
`vy/vx` and `w/vx` hold the target ratios to 1e-4 and the null space stays empty.
A non-positive limit freezes the wheels rather than meaning "unlimited".

### Bug found by the tests

**At high rates the symbol buffer, not the clock, ended each chunk.** The first
waveform run failed 2 of 77 checks: at 50 000 steps/s a 64-symbol chunk lasted
~1.26 ms instead of 2 ms. Every pulse guarantee still held and the average rate was
still exact — but short chunks quietly erode the queue lead the generator relies
on, and nothing stopped the firmware being configured into that regime. Added
`step_wave_max_full_chunk_rate()` (30 000 steps/s for 64 symbols), made
`step_gen_init()` refuse a `max_step_rate` above it, and corrected the test to
demand full-length chunks only below that limit while still checking every other
guarantee above it. The configured 7000 steps/s is far inside.

### A mistake during verification, recorded so it is not repeated

Checking that the bench variant compiles meant flipping `OMNIS_BENCH_STEP_TEST` to
1, building into a scratch directory, and restoring the header. In zsh, `status` is
a read-only special variable: `status=$?` aborted the rest of the command line, so
**the restore never ran and the header was left enabling the bench pattern.** It
was caught on the next step, before any commit or flash, and restored and verified.
Two lessons: never name a shell variable `status` here, and a restore must not sit
behind commands that can fail.

### Known limitations

- **RMT inter-transaction gap is unmeasured.** Between bursts the output idles low
  for the ISR's hand-over latency, probably tens of µs per 2 ms burst — roughly a
  1% lower effective rate. Harmless to pulse integrity; measure with a logic
  analyser.
- **Reversal dead time is up to ~8 ms** (drain + settle). Irrelevant for driving;
  it matters for balancing, where wheel speed crosses zero often.
- **`dir_invert` defaults (right side inverted) are unverified.** The bench
  pattern's FORWARD segment settles them wheel by wheel.
- `max_accel_steps_s2 = 20000` remains a placeholder until the A4988 current limits
  are set.

---

## 2026-09-15 — Stage 6: fault latch, buzzer, arming supervisor, integration

**Built:**

| File | What it does |
|---|---|
| `main/fault.{c,h}` | Pure fault latch with three clearing classes |
| `main/buzzer_pattern.{c,h}` | Pure patterns + event-over-fault priority player |
| `main/buzzer.{c,h}` | GPIO16 glue; writes the pin only on a level change |
| `main/supervisor.{c,h}` | Pure arming state machine — the one place that decides whether STEP pulses may exist |
| `main/main.c` | Rewritten cleanly: sense → judge → act → report, faults instead of halts |
| `main/omnis_params.*` | `safety` block: settle time, upright/flat thresholds, overrun limits |
| `test/test_supervisor.c` | 79 assertions |

**Result:** normal build clean, zero warnings, 242 KB; bench variant also clean.
Host tests for this commit: **6 suites, 435 assertions, 0 failures** (the Stage 7
balance suite, 28 more, passes too and ships next).

**No-RTOS compliance, checked mechanically rather than asserted.** Two scans,
both empty: (1) source grep of `main/` for any FreeRTOS call, handle type or
`freertos/` include; (2) the undefined symbols of the compiled `libmain.a` — which
catches anything reaching FreeRTOS through a macro or header — contain no
`xTask*`, `vTask*`, `xQueue*`, `xSemaphore*`, `xEventGroup*`, `xTimer*` or port
symbols. What the firmware does import is ESP-IDF driver API (`rmt_*`, `uart_*`,
`i2c_*`, `gptimer_*`, `gpio_*`, `esp_timer_*`), exactly the line drawn in Planning 1a.

### Design decisions and why

**On board Rev 2.0 the supervisor is the entire safety story.** EN# is hardwired,
so nothing else can keep a live driver from moving a wheel. Motors step only in
`ARMED_FLAT` or `ARMED_BALANCE`; every other state calls `step_gen_stop()` every
tick.

**Three fault clearing classes, chosen by what the fault implies.** FOREVER
(parameters, IMU init/calibration/comm/disagreement, step-generator init): the
robot's own sensing or setup cannot be trusted and nothing done from the radio
fixes that — reboot. UNTIL-DISARM (tilt, overrun): the hardware is fine, the
situation was not; cleared once disarmed with the switch LOW. LIVE (radio link):
present while down. Any active fault of any class blocks arming and forces a
disarm.

**Arming needs a LOW→HIGH edge, and the attempt consumes it, pass or fail.** So a
switch left HIGH at power-on can never arm, a rejected arm needs a deliberate
re-try, and — tested explicitly — the robot does not re-arm itself when a fault
clears or the link returns with the switch still up.

**Every arm check has its own rejection reason**, printed and buzzed: fault, no
link, IMU not ready, sticks not centred, pose does not match the mode, balance gains
zero. The first failing check is the one reported, ordered from "hardware is
broken" to "you asked for the wrong thing".

**Mode is latched at arming.** Moving the mode switch while armed does nothing —
changing between flat and balance mid-motion is a crash. AUTO picks balance if the
robot is tipped past 60°, flat otherwise.

**Balance is refused explicitly until Stage 7 wires the controller**
(`balance_gains_set = false`), rather than arming into a mode that does nothing.

**Boot never halts on a peripheral.** A missing IMU, a failed calibration or an
RMT failure latches a fault; the loop, buzzer and telemetry keep running so the
problem is reported. Only invalid parameters or a tick that will not start drop to
`fault_only_loop()`, because everything downstream divides by the parameters.

**The kinematics self-check now uses the fixed REFERENCE geometry**, not the
parameter set. It verifies the code and the FPU; editing geometry cannot fake a
parameter fault.

**Buzzer patterns are tested to be pairwise distinguishable** — the test compares
every pattern's timeline against every other's — and a one-shot event always plays
to completion over a fault pattern, which then restarts from its beginning so it is
heard whole.

**A dead UART must not become a log flood.** If `crsf_init()` fails, the loop never
calls `crsf_poll()`: `uart_read_bytes()` on an uninstalled driver logs an error per
call, which at 500 Hz would itself wreck the loop timing. The robot simply never
has a link, and cannot arm.

**Overrun fault, windowed, with the telemetry line excluded.** 25 missed deadlines
in a 500-tick window faults an armed robot: past 5% the loop's dt, and so the EKF
and PID, can no longer be trusted. The ticks after a log line are not counted — a
telemetry line blocks for a few ms and must not be able to trip a fault by itself.

**Link loss is a fault only once there has been a link.** Before the radio is ever
seen, the robot just cannot arm (NO_LINK); after, losing it disarms and double-chirps.

### Known limitations

- The overrun window is a fixed block, so 24 overruns either side of a boundary go
  uncounted. Adequate for catching a loop that is genuinely too slow.
- Disarming stops the wheels immediately rather than ramping down. Correct for a kill
  switch; mechanically abrupt at speed.
- The motors hold current whenever 12 V is present — hardware, not firmware (EN#).
- No battery cutoff: battery sensing is out of MVP scope.

---

## 2026-09-16 — Stage 7: balance controller and full integration

**Built:**

| File | What it does |
|---|---|
| `main/balance.{c,h}` | Lean PID in the balance frame -> grounded-pair wheel rates |
| `main/main.c` | Frame switching on arm/disarm, balance path, balance tilt fault, disarm summary |
| `main/omnis_params.*` | `balance` block extended: accel clamp, stick mapping, tilt limit, invert, tuning range |
| `main/omnis_config.h` | `OMNIS_TELEMETRY_IN_BALANCE`, `OMNIS_TUNE_KP_FROM_POT` |
| `test/test_balance.c` | 28 assertions, including a closed-loop inverted-pendulum simulation |

**Result:** normal build clean, zero warnings, 244 KB (77% free). A build with all
three optional switches on (bench pattern, live kp tuning, telemetry in balance)
also compiles clean. Host tests: **7 suites, 463 assertions, 0 failures.**
No-RTOS compliance re-checked: 44 source files clean, and none of the 185 undefined
symbols in `libmain.a` is a FreeRTOS symbol.

### The wheel sign — and an error caught while deriving it

The kinematics' `+omega` is "the sense that drives the robot forward when flat".
What that does when the robot is standing on two wheels depends on where the ground
contact sits relative to the axle, and it is **not the same for the two pairs**.

For rolling without slip the centre moves opposite to the contact point's tangential
velocity, `omega x r`:

| Pose | ground at | `omega x r` | centre moves |
|---|---|---|---|
| flat | body −Z | `(−wR, 0, 0)` | +X — forward, by definition |
| front pair down | body **+X** | `(0, 0, −wR)` | +Z = **+X′**, toward the top face |
| rear pair down | body −X | `(0, 0, +wR)` | −Z = **−X′**, away from it |

So `sigma = +1` on the front pair and `−1` on the rear.

**My first derivation put the front-pair contact at body −X and concluded `+omega`
drove the robot backward on both pairs.** Nose-down 90° puts +X *down*, so the
contact is at +X. Caught by re-deriving from the rotation matrix before any of it
reached a file. The corrected sign is one factor, applied in one place, with the
whole derivation written out in `balance.h` — because if it is wrong on the real
robot, the symptom (wheels driving away from the fall) looks identical to a
controller sign error, and the two have completely different fixes.

Left/right flips too: with `+X′` on the top face and `+Z′` up, the robot's left is
`+Y′`, which is `+Y` on the front pair but `−Y` on the rear. Balancing on the rear
pair, the "left" wheel is **RR**.

### Evidence

`test_balance.c` runs a real closed loop: an inverted pendulum whose cart
acceleration comes from the commanded wheel rates through the rolling relation
above, written out a second time in the test independently of
`balance_pair_sign()`.

| Case | Result |
|---|---|
| Released at 3°, front pair | recovers to 0.00°, peak lean 3.00°, peak wheel 1522 steps/s |
| Released at 3°, rear pair | recovers to 0.00° — the sign flip is exercised |
| Released at −3° | recovers |
| `output_invert` on a correct robot | **falls** (>30°) — the sign genuinely matters |
| Zero gains | **falls** — which is why the supervisor refuses to arm them |

What this cannot prove is that the derivation matches the physical robot. That is
the bench sign check in TESTING.md §7.3, and it is why `output_invert` exists —
with an explicit warning that if only *one* pair is wrong, the flag is the wrong
fix.

### Design decisions and why

**Arming balance switches the estimation frame, then waits.** On the arming tick
the filters are re-seeded in the balance frame (their flat-frame angles mean nothing
there) and `ARMED-BAL-SETTLE` holds the wheels still for 400 ms — two EKF time
constants — before the controller drives.

**The balance tilt fault is gated on the frame having actually switched.** On the
arming tick the estimate is still flat-frame, where standing upright reads ~85°;
without that gate every balance arm would instantly fault with TILT.

**No slew limiter in the balance path.** The controller already limits acceleration
through its PID output clamp, and a second rate limit is just added lag, which
destabilises a balancer. The flat path keeps its slew limiter, where smoothness
matters and phase margin does not.

**The deadband still applies.** A wheel dithering across zero chatters its DIR line
(kinematics reference §6), and a balancing robot sits near zero speed constantly.

**Telemetry goes silent while balancing.** A blocking log line every second is a
periodic disturbance to the loop. One summary prints on disarm — time balanced,
peak lean, final speed — and `OMNIS_TELEMETRY_IN_BALANCE` restores the stream for
tuning.

**Live kp tuning uses `balance_set_kp()`, not `balance_init()`**, because re-initialising
mid-balance clears the integrators and the forward speed, which is a fall.

**The outer velocity-bias loop is wired but off** (`vel_bias_gain = 0`), matching
planning decision 1c. Enabling it is a parameter change, not a code change.

### A test assertion that was wrong

The first version asserted that full forward stick "commands forward acceleration",
and passed only because it tested for non-zero. The truth is the opposite and more
interesting: from upright, the base must first move **backward** for the robot to
tip forward — a controlled fall is non-minimum-phase. The assertion now checks
`last_accel < 0` and says why.

### Known limitations

- **Reversal dead time (~8 ms)** while queued pulses drain. Balancing in place
  reverses often; if the robot hunts around upright, suspect this first.
- **Mecanum crab:** two grounded mecanum wheels driven differentially produce yaw
  *and* some sideways force, so turning while balancing drifts laterally.
- **No encoders**, so the robot will drift across the room (§13a). The outer loop is
  the mitigation, and it is off by default.
- **Every balance gain is unknown** until the robot is on a tether.

---

## 2026-09-16 — Build complete: summary, and where to pick it up

All seven stages are built, host-tested and committed. **Stage 1 is the only
stage verified on hardware** (500 Hz, zero overruns, 2026-09-07, on the Rev 1
board); everything since was written against an unassembled Rev 2.0 board, so the
bench procedure in `TESTING.md` is the remaining work.

### Totals

| | |
|---|---|
| Firmware | 44 files in `main/`, ~244 KB binary, 77% of the app partition free |
| Host tests | 7 suites, **463 assertions**, plus 97 in `assets/control/` |
| Builds verified | normal, bench-pattern, and all-optional-switches-on — each with **zero warnings** |
| No-RTOS rule | verified mechanically: no FreeRTOS call, handle or include in 44 sources, and none of `libmain.a`'s 185 undefined symbols |

### Bugs found, and what found them

Worth recording because the pattern is informative: **the tests and the
derivations caught more than the compiler did.**

| # | Bug | Found by | Would have looked like |
|---|---|---|---|
| 1 | `pid_t` collides with POSIX `sys/types.h` | compiling the asset on the target toolchain before porting | a hard compile error at Stage 7, blamed on the port |
| 2 | Flat-frame pitch **folds** at the balance point: 85° and 95° both read 85° | re-deriving §7 while designing the balance frame | a balancer that pushes the wrong way on one side of upright, blamed on gains |
| 3 | Chunks ended early above ~30 000 steps/s (symbol buffer, not the clock) | `test_step_wave.c` on the first run | queue lead silently eroding at high speed |
| 4 | Telemetry rate biased high (two off-by-ones) | the Stage 1 **hardware** run reading 500.13 Hz | a "healthy" loop rate that hides degradation |
| 5 | Balance wheel sign: front-pair contact is at body **+X**, not −X | re-deriving the rolling relation before writing it down | wheels driving away from the fall on one pair only |
| 6 | Test asserted forward stick commands forward acceleration | reading the assertion's own output | a tautological test passing forever |

Two process mishaps, both caught before any commit: zsh's read-only `$status`
aborted a command line and left the bench flag enabled in a working file; and two
parallel shell calls shared one working directory, so a build ran in the wrong
place and a "clean" compliance scan had actually scanned nothing.

### Every stage, and the commit it landed in

Carried over from `PLAN.md` §6 when that file was folded into this one
(2026-09-16). Each stage was committed separately, with its reasoning in the
dated entry above.

| Stage | Commit | Built | Host-tested | On hardware |
|---|---|---|---|---|
| 1 Skeleton, pins, params, 500 Hz tick | `5417f0e`, `c59b800` | ✅ | — | ✅ 500.0 Hz, zero overruns, no jitter |
| 2 Kinematics port + RC mapping | `ce1ed5e` | ✅ | 89 assertions | ✅ boot self-check on the FPU |
| 3 MPU6050 + EKF + fusion | `4343cfe` | ✅ | 125 assertions | ⬜ |
| 4 CRSF parser + RC input | `c207829` | ✅ | 55 assertions | ⬜ |
| 5 RMT step generation | `b3cd4a7` | ✅ | 100 assertions | ⬜ |
| 6 Faults, buzzer, supervisor | `d2ae99a` | ✅ | 79 assertions | ⬜ |
| 7 Balance + integration | `ef6a6a5` | ✅ | 28 assertions | ⬜ |

> The hashes in this table were regenerated on 2026-09-16 when the history was
> rewritten to remove the `Co-Authored-By` trailers from every commit message.
> Commit contents and dates are unchanged; only the hashes moved.

Supporting commits: the Rev 2.0 pinout migration (`89d6120`) and two latent-bug
fixes in `assets/control/` found before porting (`4952f1d`). The kinematics
re-derivation for the parallel roller layout came later (`949a173`, `32cf246`,
`0fdb93f`, `ece97a0`).

### What was delivered against the original scope

| Promised | Delivered |
|---|---|
| 500 Hz balance/EKF loop, dual-IMU, inverse-covariance weighted, >15° fault | ✅ — plus a balance-frame fix the original scope did not anticipate |
| 4-wheel mecanum IK/FK, verified equations, unchanged | ✅ byte-identical port — later re-derived, once the wheels turned out not to be in an X-drive |
| CRSF parser, throttle→vx, yaw→w, pitch+roll→vy/vx | ✅ plus link-loss failsafe, arm/mode/speed switches, RX-pin auto-detect |
| STEP generation via RMT only, nothing in the hot path | ✅ four channels, burst re-arm, exact queue regulation |
| Buzzer fault/failsafe indicator | ✅ plus a full fault latch and arming supervisor |
| Excluded: OLED, buttons, SD, OTA, any RTOS primitive | ✅ none implemented, none stubbed; no-RTOS verified mechanically |

### Decisions, as settled

**1a** ESP-IDF, no RTOS primitive in OMNIS-authored code (Arduino rejected on
evidence) · **1b** RMT Option B, burst re-arm · **1c** inner balance PID in,
outer velocity-bias loop wired but off by default. The reasoning for each is in
the 2026-09-05 Planning entry at the top of this file, which is what the
`PLAN.md §1a` / `§1b` / `decision 1c` citations throughout the source now refer
to.

### Open items carried to the bench

Questions 5 and 6 from the original plan — the CRSF kill-switch channel
(default: ch 6, HIGH = armed) and the RC scaling constants (300 / 150 / 300 /
1.5) — carry stated defaults to be confirmed on the bench at the stage that uses
them. Every other planning question was closed during the build.

### Where to pick this up

1. **Set the A4988 current limits (Vref) before connecting 12 V.** `EN#` is
   hardwired on Rev 2.0 — the motors energise the instant power is applied.
2. Work through `TESTING.md` in order. Stages 3–6 need only USB and a radio;
   Stage 5 onward needs the wheels off the ground.
3. The four things most likely to need changing, all parameters, none code:
   IMU mount constants (Stage 3.3 wizard), motor `dir_invert` flags (Stage 5.1),
   radio channel map and stick polarity (Stage 4.1), balance gains (Stage 7.4).
4. `BUILD-LOG.md` (this file) explains why each decision was made, and since
   2026-09-16 also carries the scope and the settled decisions that used to live
   in `PLAN.md`. The project info file is at `../assets/documentation/omnis-info.md`
   — one copy for the whole project, with per-section notes on what this build does.

### What this build deliberately leaves for the FreeRTOS version

OLED and buttons, microSD and `params.json`, logging, OTA and Wi-Fi, battery
sensing — and the custom RTOS layer itself. Every pure module here (kinematics,
EKF, fusion, PID, balance, CRSF parser, fault/supervisor logic, waveform
generator) has no ESP-IDF dependency and carries over unchanged; only the glue
(`main.c`, `imu.c`, `crsf.c`, `step_gen.c`, `buzzer.c`) is superloop-shaped.

---

## 2026-09-16 — Wheel layout change: kinematics re-derived for parallel rollers

The wheels turned out **not** to be in the X-drive arrangement every document in
this repository had assumed. Mounting-shaft and motor constraints put the same
roller tilt on **both left wheels** and the mirrored tilt on **both right
wheels**:

```
        FL  /                 \  FR          left  pair  FL, RL  ->  δ = -1
        RL  /                 \  RR          right pair  FR, RR  ->  δ = +1
```

### Re-derived, not sign-flipped

The temptation with a change like this is to flip signs until the bench test
passes. That was rejected: the `vy` signs and the yaw lever arms both descend
from the same `δ_i`, so patching one column by hand produces a matrix that is
not the kinematics of any physical robot, and the error only shows up later as
drift. The derivation was redone from the rigid-body contact-patch velocity
onward.

The general per-wheel constraint survived untouched:

```
r*ω_i  =  vx  +  δ_i*vy  +  w*(δ_i*x_i − y_i)
```

Everything specific to the robot is now **which four signs go into δ**, and the
firmware mirrors that: `MECANUM_DELTA_FL` … `MECANUM_DELTA_RR` are the only
statement of the layout, and both lever arms are computed from them by
`mecanum_yaw_levers()`. A mirrored build is a four-line change; a half-applied
mirror is not expressible.

### What actually moved

| | Was (X-drive) | Now |
|---|---|---|
| Shared tilt | FL+RR, FR+RL | **FL+RL, FR+RR** |
| Yaw lever | `±k` on all four | **`±k` front, `±m` rear**, `k=(L+W)/2`, `m=(L−W)/2` |
| Rear IK rows | `vx + vy ∓ k*w` | **`vx − vy ± m*w`** |
| Strafe pattern | diagonals | **sides**, equal magnitude |
| Bench idle test | `vx=vy` idles FL and RR | **idles the whole LEFT SIDE** |
| `MᵀM` | diagonal | **not diagonal** — `c_vy · c_w = 2W` |
| FK yaw scale | `r/(2(L+W))` | **`r/(2L)`** — track width drops out |
| FK structure | yaw ← sides, strafe ← diagonals | **yaw ← Δ_F − Δ_R, strafe ← weighted Δ_F + Δ_R** |

**Only the rear pair changed.** Both front-wheel equations are identical to the
previous edition, which was the fastest way to check the port had been applied
consistently rather than half-applied.

### Three results worth recording

**The layout is holonomic for every real chassis.** Working the pseudoinverse
through gives `det(MᵀM) = 4L²` — the track width cancels completely. There is no
aspect ratio, square included, at which this drivetrain loses a degree of
freedom. That matters because the rear yaw lever `(L−W)/2` is only −3.5 mm on
this frame and *looks* singular; it is not. The rear pair stops contributing to
yaw at `L = W` while still contributing to strafe, and rank is preserved.

**It costs nothing in performance and something in precision.** The peak wheel
rate per unit of commanded motion is identical to the X-drive on all three axes,
so the same step-rate ceiling buys the same top speed, strafe speed and yaw
rate — this was checked rather than assumed, and is now a test. What it costs is
odometry: the strafe and yaw columns meet at 44.1° instead of 90°, amplifying
per-wheel error by **1.44× on `vy` and 2.03× on `w`**.

**The null space did not move.** `(+1, +1, −1, −1)` still annihilates all three
motion columns — the solve uses only `k ≠ m`, i.e. `W ≠ 0`, so it holds for
either handedness and any geometry. `mecanum_null_space()` needed no edit at all
and the health metric keeps its meaning. Of everything here that was the one
pleasant surprise.

### Verification

- The closed-form pseudoinverse was checked against `(MᵀM)⁻¹Mᵀ` computed in
  **exact rational arithmetic**, for both handedness signs and four geometries
  (223×230, 300×200, 250×250 square, 100×400). Every coefficient matched
  exactly, with no floating point in the comparison. Doing this before writing
  the closed form into the code and three documents was the right order — the
  hand algebra had already produced one wrong intermediate (`2(k+m)` where the
  dot product is `2(k−m)`), which the check would have caught had the prose
  survived that far.
- `test_kinematics.c` gained a layout-properties section: per-axis round trips
  (a rank-deficient layout fails only one axis, so a combined test can mask it),
  the lever identities `κ_F + κ_R = −W` and `κ_F − κ_R = −L`, the 64.7:1 ratio,
  the square-frame zero and the sign flip at `L > W`, the non-orthogonality
  `c_vy · c_w = 2W = 460`, and the unchanged null space asserted against the
  columns themselves rather than against commands the IK happened to produce.
- The boot self-check now asserts the rear pair at ±59.418 steps/s for a 1 rad/s
  spin. **An X-drive build would show ±3845 on all four**, so that one line
  catches a stale port on the hardware.
- Both diagonals are now bench-tested. `vx = vy` idles the left side and
  `vx = −vy` idles the right; running *both* is what separates "handedness
  correct" from "handedness mirrored", since a mirrored build passes one and
  fails the other.

### The convention problem, stated honestly

A roller glyph `/` or `\` can mean the roller's **axis** or its **rolling
direction**, and the two readings are mirror images. Picking one consistently is
not the same as being right about the hardware, and the difference is not
academic — it flips which way the robot strafes.

The derivation now fixes the convention explicitly in §2 (the glyph is the
**axis**, seen from above, robot facing up the page, body +y to the page-left)
and §5.3 carries the bench test that settles it on the physical robot, along
with the exact four-constant fix. This is deliberately *not* left as a judgement
call in prose: the code has one place to change and the test has a
pass/fail answer.

### Documents rewritten

All three kinematics documents were rewritten rather than patched —
`derivation.md` (second edition, re-derived from §4 onward, with a new §9.3 on
conditioning and a §13 reviewer's checklist of what moved), `reference.md`, and
`code-explained.md` (whose verification transcript is now real output from the
shipped source). `TESTING.md` Stages 5.1 and 7.1, both copies of `omnis-info.md`,
`omnis_imu_mounting.h` (the IMUs sit on the FL/RR diagonal, which *was* a
handedness pair and is not one now), the root `README.md` and `PLAN.md`'s (now folded into this file)
corner-labelling note were all brought into line.

`OPERATIONS_GUIDE.md` was added in the same pass: build and flash, the superloop
walkthrough, a file-by-file index of all 44 sources, and a tuning cheat sheet
whose §4.2 is the "forward is right but strafe is backwards" procedure.

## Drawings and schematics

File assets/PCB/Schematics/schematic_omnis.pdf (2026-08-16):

# G$1 GND

## POWER SUPPLY

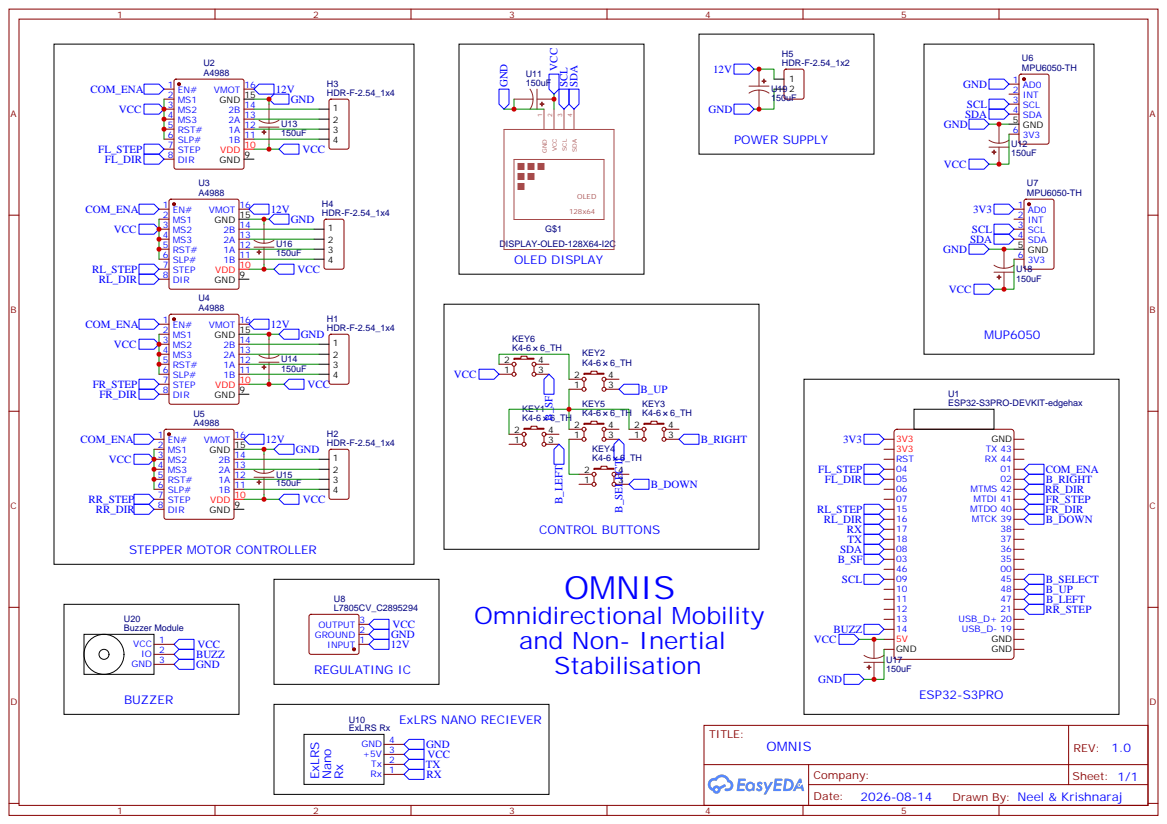
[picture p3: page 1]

Drawn By: Neel & Krishnaraj

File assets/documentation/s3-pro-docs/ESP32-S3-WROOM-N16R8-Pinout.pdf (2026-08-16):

# ESP32 S3 WROOM N16R8 Dev Kit Pinout

# ESP32 S3 Pinout

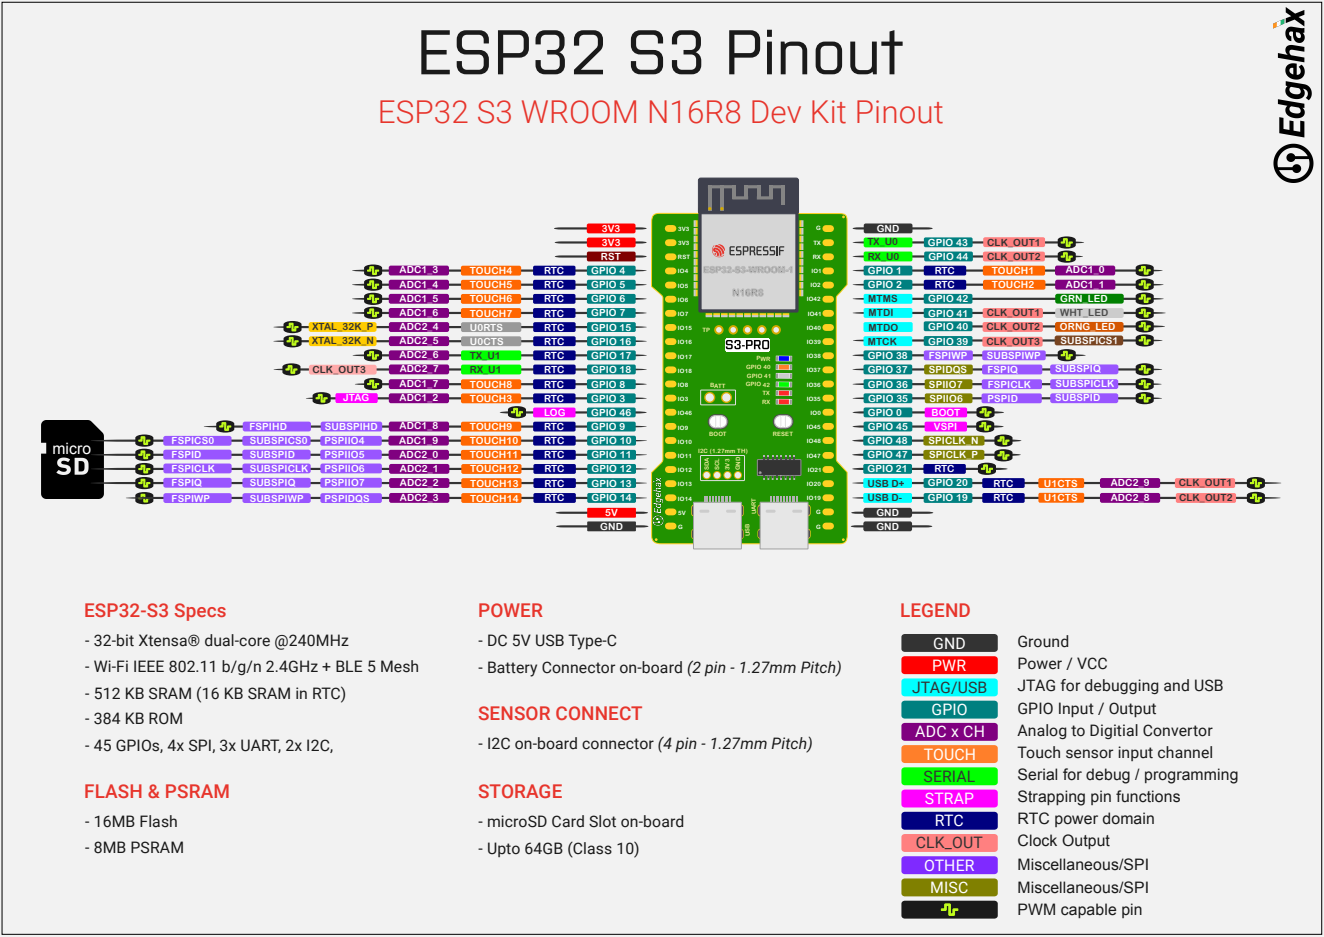
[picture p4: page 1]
SENSOR CONNECT; - 45 GPIOs, 4x SPI, 3x UART, 2x I2C,; - I2C on-board connector (4 pin - 1.27mm Pitch); FLASH & PSRAM; - 16MB Flash - 8MB PSRAM; RST; USB; UART; I2C (1.27mm TH) SDA SCL 3V³ GND; BOOT; RESET; BATT; PWR GPIO 40 GPIO 41 GPIO 42 TX RX; ESP32-S3-WROOM-1; GND; FSPIWP; SUBSPIWP; PSPIDQS; ADC2_3; TOUCH14; RTC; GPIO 14; ADC2_2; TOUCH13; GPIO 13; micro; FSPIQ; SUBSPIQ; PSPIIO7; FSPICLK; SUBSPICLK; PSPIIO6; ADC2_1; TOUCH12; GPIO 12; FSPID; SUBSPID; PSPIIO5; ADC2_0; TOUCH11; GPIO 11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

ESP32-S3 Specs
- 32-bit Xtensa® dual-core @240MHz
- Wi-Fi IEEE 802.11 b/g/n 2.4GHz + BLE 5 Mesh
- 512 KB SRAM (16 KB SRAM in RTC)
- 384 KB ROM

POWER
- DC 5V USB Type-C
- Battery Connector on-board (2 pin - 1.27mm Pitch)

STORAGE
- microSD Card Slot on-board
- Upto 64GB (Class 10)

PWM capable pin

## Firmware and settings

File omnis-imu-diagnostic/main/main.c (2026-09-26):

#include <stdio.h>
#include <stdint.h>
#include <stdbool.h>

#include "freertos/FreeRTOS.h"
#include "freertos/task.h"

#include "driver/i2c_master.h"
#include "esp_err.h"

/* ============================================================
 * OMNIS REV 2.0
 * MPU6050 / MPU6500 / MPU6515 IDENTITY TEST
 *
 * SDA  = GPIO8
 * SCL  = GPIO9
 *
 * IMU-A = 0x68
 * IMU-B = 0x69
 * ============================================================ */

#define I2C_PORT        I2C_NUM_0
#define I2C_SDA_GPIO    GPIO_NUM_8
#define I2C_SCL_GPIO    GPIO_NUM_9

#define I2C_FREQ_HZ     400000
#define I2C_TIMEOUT_MS  100

#define IMU_A_ADDR      0x68
#define IMU_B_ADDR      0x69

/* ============================================================
 * WHO_AM_I values
 * ============================================================ */

#define WHOAMI_MPU6050  0x68
#define WHOAMI_MPU6500  0x70
#define WHOAMI_MPU6515  0x74

/* ============================================================
 * Common MPU registers
 * ============================================================ */

#define REG_SMPLRT_DIV          0x19
#define REG_CONFIG              0x1A
#define REG_GYRO_CONFIG         0x1B
#define REG_ACCEL_CONFIG        0x1C
#define REG_ACCEL_CONFIG2       0x1D

#define REG_FIFO_EN             0x23

#define REG_INT_PIN_CFG         0x37
#define REG_INT_ENABLE          0x38
#define REG_INT_STATUS          0x3A

#define REG_ACCEL_XOUT_H        0x3B
#define REG_TEMP_OUT_H          0x41
#define REG_GYRO_XOUT_H         0x43

#define REG_EXT_SENS_DATA_00    0x49

#define REG_ACCEL_INTEL_CTRL    0x69

#define REG_USER_CTRL           0x6A
#define REG_PWR_MGMT_1          0x6B
#define REG_PWR_MGMT_2          0x6C

#define REG_FIFO_COUNTH         0x72
#define REG_FIFO_COUNTL         0x73
#define REG_FIFO_R_W            0x74

#define REG_WHO_AM_I            0x75

/* MPU6500 / MPU6515 extended registers */

#define REG_XG_OFFS_TC          0x00
#define REG_YG_OFFS_TC          0x01
#define REG_ZG_OFFS_TC          0x02

#define REG_X_FINE_GAIN         0x03
#define REG_Y_FINE_GAIN         0x04
#define REG_Z_FINE_GAIN         0x05

#define REG_XA_OFFS_H           0x06
#define REG_XA_OFFS_L           0x07
#define REG_YA_OFFS_H           0x08
#define REG_YA_OFFS_L           0x09
#define REG_ZA_OFFS_H           0x0A
#define REG_ZA_OFFS_L           0x0B

#define REG_PRODUCT_ID          0x0C

#define REG_SELF_TEST_X_GYRO   0x00
#define REG_SELF_TEST_Y_GYRO   0x01
#define REG_SELF_TEST_Z_GYRO   0x02

#define REG_SELF_TEST_X_ACCEL   0x0D
#define REG_SELF_TEST_Y_ACCEL   0x0E
#define REG_SELF_TEST_Z_ACCEL   0x0F

#define REG_XG_OFFS_USRH        0x13
#define REG_XG_OFFS_USRL        0x14
#define REG_YG_OFFS_USRH        0x15
#define REG_YG_OFFS_USRL        0x16
#define REG_ZG_OFFS_USRH        0x17
#define REG_ZG_OFFS_USRL        0x18

#define REG_ACCEL_XOFFS_H       0x77
#define REG_ACCEL_YOFFS_H       0x7A
#define REG_ACCEL_ZOFFS_H       0x7D

/* ============================================================
 * I2C helpers
 * ============================================================ */

static esp_err_t read_reg(
    i2c_master_dev_handle_t dev,
    uint8_t reg,
    uint8_t *value)
{
    return i2c_master_transmit_receive(
        dev,
        &reg,
        1,
        value,
        1,
        I2C_TIMEOUT_MS
    );
}

static esp_err_t write_reg(
    i2c_master_dev_handle_t dev,
    uint8_t reg,
    uint8_t value)
{
    uint8_t data[2] = {
        reg,
        value
    };

    return i2c_master_transmit(
        dev,
        data,
        2,
        I2C_TIMEOUT_MS
    );
}

static uint8_t read8(
    i2c_master_dev_handle_t dev,
    uint8_t reg)
{
    uint8_t value = 0xFF;

    if (read_reg(dev, reg, &value) != ESP_OK) {
        return 0xFF;
    }

    return value;
}

/* ============================================================
 * Print register
 * ============================================================ */

static void show_reg(
    i2c_master_dev_handle_t dev,
    uint8_t reg,
    const char *name)
{
    uint8_t value = 0;

    esp_err_t err =
        read_reg(
            dev,
            reg,
            &value
        );

    if (err == ESP_OK) {

        printf(
            "  0x%02X %-24s = 0x%02X\n",
            reg,
            name,
            value
        );

    } else {

        printf(
            "  0x%02X %-24s = ERROR %s\n",
            reg,
            name,
            esp_err_to_name(err)
        );
    }
}

/* ============================================================
 * Identify device
 * ============================================================ */

static const char *identify(
    uint8_t who)
{
    switch (who) {

        case WHOAMI_MPU6050:
            return "MPU6050";

        case WHOAMI_MPU6500:
            return "MPU6500";

        case WHOAMI_MPU6515:
            return "MPU6515";

        default:
            return "UNKNOWN";
    }
}

/* ============================================================
 * Raw sensor data
 * ============================================================ */

typedef struct
{
    int16_t ax;
    int16_t ay;
    int16_t az;

    int16_t temp;

    int16_t gx;
    int16_t gy;
    int16_t gz;

} imu_raw_t;

static esp_err_t read_raw(
    i2c_master_dev_handle_t dev,
    imu_raw_t *raw)
{
    uint8_t reg = REG_ACCEL_XOUT_H;
    uint8_t data[14];

    esp_err_t err =
        i2c_master_transmit_receive(
            dev,
            &reg,
            1,
            data,
            sizeof(data),
            I2C_TIMEOUT_MS
        );

    if (err != ESP_OK) {
        return err;
    }

    raw->ax =
        (int16_t)((data[0] << 8) | data[1]);

    raw->ay =
        (int16_t)((data[2] << 8) | data[3]);

    raw->az =
        (int16_t)((data[4] << 8) | data[5]);

    raw->temp =
        (int16_t)((data[6] << 8) | data[7]);

    raw->gx =
        (int16_t)((data[8] << 8) | data[9]);

    raw->gy =
        (int16_t)((data[10] << 8) | data[11]);

    raw->gz =
        (int16_t)((data[12] << 8) | data[13]);

    return ESP_OK;
}

static void print_raw(
    imu_raw_t *r)
{
    printf(
        "  ACC  raw: X=%6d Y=%6d Z=%6d\n",
        r->ax,
        r->ay,
        r->az
    );

    printf(
        "  TEMP raw: %6d\n",
        r->temp
    );

    printf(
        "  GYRO raw: X=%6d Y=%6d Z=%6d\n",
        r->gx,
        r->gy,
        r->gz
    );
}

/* ============================================================
 * Basic configuration
 * ============================================================ */

static void configure_common(
    i2c_master_dev_handle_t dev)
{
    printf(
        "\nWriting common MPU configuration...\n"
    );

    /*
     * PLL X gyro
     */
    write_reg(
        dev,
        REG_PWR_MGMT_1,
        0x01
    );

    /*
     * All accel + gyro axes enabled
     */
    write_reg(
        dev,
        REG_PWR_MGMT_2,
        0x00
    );

    /*
     * DLPF
     */
    write_reg(
        dev,
        REG_CONFIG,
        0x02
    );

    /*
     * 500 Hz sample rate
     */
    write_reg(
        dev,
        REG_SMPLRT_DIV,
        0x01
    );

    /*
     * Gyro ±500 dps
     */
    write_reg(
        dev,
        REG_GYRO_CONFIG,
        0x08
    );

    /*
     * Accel ±4 g
     */
    write_reg(
        dev,
        REG_ACCEL_CONFIG,
        0x08
    );

    /*
     * MPU6500/6515 has ACCEL_CONFIG2.
     *
     * 0x00 selects normal accelerometer filtering.
     */
    write_reg(
        dev,
        REG_ACCEL_CONFIG2,
        0x00
    );

    /*
     * I2C bypass
     */
    write_reg(
        dev,
        REG_INT_PIN_CFG,
        0x40
    );

    /*
     * No interrupts
     */
    write_reg(
        dev,
        REG_INT_ENABLE,
        0x00
    );

    vTaskDelay(
        pdMS_TO_TICKS(20)
    );
}

/* ============================================================
 * Configuration readback
 * ============================================================ */

static void configuration_dump(
    i2c_master_dev_handle_t dev)
{
    printf(
        "\nCommon configuration readback:\n"
    );

    show_reg(
        dev,
        REG_PWR_MGMT_1,
        "PWR_MGMT_1"
    );

    show_reg(
        dev,
        REG_PWR_MGMT_2,
        "PWR_MGMT_2"
    );

    show_reg(
        dev,
        REG_CONFIG,
        "CONFIG"
    );

    show_reg(
        dev,
        REG_SMPLRT_DIV,
        "SMPLRT_DIV"
    );

    show_reg(
        dev,
        REG_GYRO_CONFIG,
        "GYRO_CONFIG"
    );

    show_reg(
        dev,
        REG_ACCEL_CONFIG,
        "ACCEL_CONFIG"
    );

    show_reg(
        dev,
        REG_ACCEL_CONFIG2,
        "ACCEL_CONFIG2"
    );

    show_reg(
        dev,
        REG_INT_PIN_CFG,
        "INT_PIN_CFG"
    );

    show_reg(
        dev,
        REG_INT_ENABLE,
        "INT_ENABLE"
    );
}

/* ============================================================
 * MPU6515-specific fingerprint
 * ============================================================ */

static void mpu6515_fingerprint(
    i2c_master_dev_handle_t dev)
{
    printf("\n");
    printf("============================================================\n");
    printf("MPU6500 / MPU6515 EXTENDED FINGERPRINT\n");
    printf("============================================================\n");

    printf(
        "\nSelf-test / factory-related registers:\n"
    );

    show_reg(
        dev,
        REG_SELF_TEST_X_GYRO,
        "XG_ST_DATA"
    );

    show_reg(
        dev,
        REG_SELF_TEST_Y_GYRO,
        "YG_ST_DATA"
    );

    show_reg(
        dev,
        REG_SELF_TEST_Z_GYRO,
        "ZG_ST_DATA"
    );

    show_reg(
        dev,
        REG_SELF_TEST_X_ACCEL,
        "XA_ST_DATA"
    );

    show_reg(
        dev,
        REG_SELF_TEST_Y_ACCEL,
        "YA_ST_DATA"
    );

    show_reg(
        dev,
        REG_SELF_TEST_Z_ACCEL,
        "ZA_ST_DATA"
    );

    show_reg(
        dev,
        REG_PRODUCT_ID,
        "PRODUCT_ID"
    );

    printf(
        "\nFactory offset / extended registers:\n"
    );

    show_reg(
        dev,
        REG_XG_OFFS_USRH,
        "XG_OFFS_USRH"
    );

    show_reg(
        dev,
        REG_XG_OFFS_USRL,
        "XG_OFFS_USRL"
    );

    show_reg(
        dev,
        REG_YG_OFFS_USRH,
        "YG_OFFS_USRH"
    );

    show_reg(
        dev,
        REG_YG_OFFS_USRL,
        "YG_OFFS_USRL"
    );

    show_reg(
        dev,
        REG_ZG_OFFS_USRH,
        "ZG_OFFS_USRH"
    );

    show_reg(
        dev,
        REG_ZG_OFFS_USRL,
        "ZG_OFFS_USRL"
    );

    printf(
        "\nAccelerometer offset registers:\n"
    );

    show_reg(
        dev,
        REG_ACCEL_XOFFS_H,
        "XA_OFFS_H"
    );

    show_reg(
        dev,
        REG_ACCEL_YOFFS_H,
        "YA_OFFS_H"
    );

    show_reg(
        dev,
        REG_ACCEL_ZOFFS_H,
        "ZA_OFFS_H"
    );
}

/* ============================================================
 * Reset + identity
 * ============================================================ */

static void reset_identity_test(
    i2c_master_dev_handle_t dev)
{
    printf("\n");
    printf("============================================================\n");
    printf("RESET + WHO_AM_I TEST\n");
    printf("============================================================\n");

    uint8_t before =
        read8(
            dev,
            REG_WHO_AM_I
        );

    printf(
        "WHO_AM_I before reset = 0x%02X (%s)\n",
        before,
        identify(before)
    );

    printf(
        "Writing PWR_MGMT_1 = 0x80...\n"
    );

    esp_err_t err =
        write_reg(
            dev,
            REG_PWR_MGMT_1,
            0x80
        );

    if (err != ESP_OK) {

        printf(
            "Reset write failed: %s\n",
            esp_err_to_name(err)
        );

        return;
    }

    vTaskDelay(
        pdMS_TO_TICKS(100)
    );

    uint8_t pwr =
        read8(
            dev,
            REG_PWR_MGMT_1
        );

    uint8_t after =
        read8(
            dev,
            REG_WHO_AM_I
        );

    printf(
        "PWR_MGMT_1 after reset = 0x%02X\n",
        pwr
    );

    printf(
        "WHO_AM_I after reset   = 0x%02X (%s)\n",
        after,
        identify(after)
    );

    if (after == before) {

        printf(
            "WHO_AM_I stability: PASS\n"
        );

    } else {

        printf(
            "WHO_AM_I stability: FAIL\n"
        );
    }
}

/* ============================================================
 * Data test
 * ============================================================ */

static void data_test(
    i2c_master_dev_handle_t dev)
{
    printf("\n");
    printf("============================================================\n");
    printf("RAW SENSOR DATA TEST\n");
    printf("============================================================\n");

    for (int i = 0; i < 10; i++) {

        imu_raw_t raw;

        esp_err_t err =
            read_raw(
                dev,
                &raw
            );

        if (err != ESP_OK) {

            printf(
                "Sample %d ERROR: %s\n",
                i + 1,
                esp_err_to_name(err)
            );

        } else {

            printf(
                "Sample %02d: "
                "A[%6d %6d %6d] "
                "G[%6d %6d %6d] "
                "T[%6d]\n",

                i + 1,

                raw.ax,
                raw.ay,
                raw.az,

                raw.gx,
                raw.gy,
                raw.gz,

                raw.temp
            );
        }

        vTaskDelay(
            pdMS_TO_TICKS(100)
        );
    }
}

/* ============================================================
 * Device test
 * ============================================================ */

static void test_device(
    i2c_master_dev_handle_t dev,
    uint8_t addr)
{
    printf("\n\n");
    printf(
        "################################################################\n"
    );

    printf(
        "### DEVICE TEST — 0x%02X\n",
        addr
    );

    printf(
        "################################################################\n"
    );

    uint8_t who =
        read8(
            dev,
            REG_WHO_AM_I
        );

    printf(
        "\nWHO_AM_I = 0x%02X\n",
        who
    );

    printf(
        "Detected identity = %s\n",
        identify(who)
    );

    if (who == WHOAMI_MPU6515) {

        printf(
            "\n*** MPU6515 ID DETECTED ***\n"
        );

        printf(
            "This device matches the MPU6515 WHO_AM_I value.\n"
        );
    }

    reset_identity_test(
        dev
    );

    configure_common(
        dev
    );

    configuration_dump(
        dev
    );

    mpu6515_fingerprint(
        dev
    );

    data_test(
        dev
    );

    printf("\n");
    printf(
        "################################################################\n"
    );

    printf(
        "### END DEVICE TEST — 0x%02X\n",
        addr
    );

    printf(
        "################################################################\n"
    );
}

/* ============================================================
 * Main
 * ============================================================ */

void app_main(void)
{
    printf("\n");
    printf(
        "============================================================\n"
    );

    printf(
        "OMNIS REV 2.0\n"
        "MPU6050 / MPU6500 / MPU6515 CONFIRMATION TEST\n"
    );

    printf(
        "============================================================\n"
    );

    printf(
        "SDA       = GPIO8\n"
        "SCL       = GPIO9\n"
        "I2C       = 400 kHz\n"
        "IMU-A     = 0x68\n"
        "IMU-B     = 0x69\n"
    );

    printf(
        "============================================================\n"
    );

    /* --------------------------------------------------------
     * I2C bus
     * -------------------------------------------------------- */

    i2c_master_bus_config_t bus_cfg = {
        .i2c_port = I2C_PORT,

        .sda_io_num = I2C_SDA_GPIO,
        .scl_io_num = I2C_SCL_GPIO,

        .clk_source = I2C_CLK_SRC_RC_FAST,

        .flags = {
            .enable_internal_pullup = false,
            .allow_pd = false,
        },
    };

    i2c_master_bus_handle_t bus = NULL;

    esp_err_t err =
        i2c_new_master_bus(
            &bus_cfg,
            &bus
        );

    if (err != ESP_OK) {

        printf(
            "I2C bus creation failed: %s\n",
            esp_err_to_name(err)
        );

        return;
    }

    printf(
        "I2C bus created successfully\n"
    );

    /* --------------------------------------------------------
     * IMU A
     * -------------------------------------------------------- */

    i2c_device_config_t dev_cfg_a = {
        .dev_addr_length = I2C_ADDR_BIT_LEN_7,
        .device_address = IMU_A_ADDR,
        .scl_speed_hz = I2C_FREQ_HZ,
    };

    i2c_master_dev_handle_t imu_a = NULL;

    err =
        i2c_master_bus_add_device(
            bus,
            &dev_cfg_a,
            &imu_a
        );

    if (err != ESP_OK) {

        printf(
            "0x68 device creation failed: %s\n",
            esp_err_to_name(err)
        );

        return;
    }

    /* --------------------------------------------------------
     * IMU B
     * -------------------------------------------------------- */

    i2c_device_config_t dev_cfg_b = {
        .dev_addr_length = I2C_ADDR_BIT_LEN_7,
        .device_address = IMU_B_ADDR,
        .scl_speed_hz = I2C_FREQ_HZ,
    };

    i2c_master_dev_handle_t imu_b = NULL;

    err =
        i2c_master_bus_add_device(
            bus,
            &dev_cfg_b,
            &imu_b
        );

    if (err != ESP_OK) {

        printf(
            "0x69 device creation failed: %s\n",
            esp_err_to_name(err)
        );

        return;
    }

    /* --------------------------------------------------------
     * Probe
     * -------------------------------------------------------- */

    printf("\n");
    printf(
        "I2C ADDRESS PROBE\n"
    );

    err =
        i2c_master_probe(
            bus,
            IMU_A_ADDR,
            I2C_TIMEOUT_MS
        );

    printf(
        "  0x68 = %s\n",
        err == ESP_OK ?
            "ACK" :
            esp_err_to_name(err)
    );

    err =
        i2c_master_probe(
            bus,
            IMU_B_ADDR,
            I2C_TIMEOUT_MS
        );

    printf(
        "  0x69 = %s\n",
        err == ESP_OK ?
            "ACK" :
            esp_err_to_name(err)
    );

    /* --------------------------------------------------------
     * 0x68 first
     * -------------------------------------------------------- */

    test_device(
        imu_a,
        IMU_A_ADDR
    );

    /* --------------------------------------------------------
     * 0x69 reference
     * -------------------------------------------------------- */

    test_device(
        imu_b,
        IMU_B_ADDR
    );

    /* --------------------------------------------------------
     * Final
     * -------------------------------------------------------- */

    printf("\n");
    printf(
        "============================================================\n"
    );

    printf(
        "MPU FAMILY CONFIRMATION TEST COMPLETE\n"
    );

    printf(
        "============================================================\n"
    );

    printf(
        "Production OMNIS firmware was not modified.\n"
    );

    while (1) {

        vTaskDelay(
            pdMS_TO_TICKS(1000)
        );
    }
}

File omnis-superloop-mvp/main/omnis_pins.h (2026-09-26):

/**
 * @file    omnis_pins.h
 * @brief   GPIO map for the OMNIS superloop MVP — board Rev 2.0.
 *
 * SOURCE OF TRUTH: assets/pcb/OMNIS.kicad_sch (Rev 2.0, supplied 2026-09-15).
 * Every assignment below was traced pin-by-pin through the schematic's wire
 * segments to its global label, not read off a picture. One place, named
 * constants, no bare GPIO numbers anywhere else in this build.
 *
 * Rev 2.0 changes firmware BEHAVIOUR, not just numbers:
 *
 *   1. COM_ENA IS GONE. All four A4988 EN# pins are hardwired to GND
 *      (assets/pcb/rev2-pin-assignment.md §3). The drivers cannot be disabled
 *      in software: whenever 12 V is present, all four motors are energised and
 *      holding. The firmware failsafe is therefore "stop generating STEP
 *      pulses" — the motors hold position, they do not go limp.
 *   2. Buzzer moved 14 -> 16 (GPIO14 belongs to the onboard microSD).
 *
 * The planning doc assets/pcb/rev2-pin-assignment.md disagrees with the final
 * schematic on seven nets. The schematic wins; the doc is older:
 *
 *     net          schematic   planning doc
 *     FR_STEP       1          38
 *     FR_DIR       38          40
 *     BL_DIR       46          41
 *     B_SF         39          48
 *     B_LEFT       41          46
 *     B_RIGHT      47          39
 *     B_SELECT     48          47
 */

#ifndef OMNIS_PINS_H
#define OMNIS_PINS_H

#include "driver/gpio.h"

/* --- Stepper enable: does not exist on Rev 2.0 ---------------------------
 * EN# is tied to GND. Kept as a named constant set to GPIO_NUM_NC so that code
 * which wants to disable the drivers can test for it, and so that restoring the
 * line later (the plan's hedge: a cuttable EN# link rewired to GPIO0/3/45) is a
 * one-line change here rather than a hunt through the codebase.
 * ------------------------------------------------------------------------ */
#define PIN_STEPPER_EN          GPIO_NUM_NC

/* --- A4988 STEP / DIR, one pair per wheel --------------------------------
 * Firmware corner names are the kinematics names FL / FR / RL / RR. The
 * schematic calls the rear wheels "back": BL = RL, BR = RR. Front is the OLED /
 * button end (assets/kinematics/mecanum-kinematics-reference.md §4).
 * ------------------------------------------------------------------------ */
#define PIN_FL_STEP             GPIO_NUM_4    /* FL_STEP */
#define PIN_FL_DIR              GPIO_NUM_5    /* FL_DIR  */
#define PIN_FR_STEP             GPIO_NUM_1   /* FR_STEP */
#define PIN_FR_DIR              GPIO_NUM_38   /* FR_DIR  */
#define PIN_RL_STEP             GPIO_NUM_15   /* BL_STEP */
#define PIN_RL_DIR              GPIO_NUM_46   /* BL_DIR, STRAPPING PIN */
#define PIN_RR_STEP             GPIO_NUM_21   /* BR_STEP */
#define PIN_RR_DIR              GPIO_NUM_2   /* BR_DIR */

/* Pin hazards worth knowing before a wheel misbehaves:
 *
 * GPIO1 carries FR_STEP and GPIO2 carries BR_DIR on the revised PCB. Older
 *   documentation listed these motor signals on GPIO40 and GPIO42.
 *
 * GPIO46 (RL_DIR) is a strapping pin sampled at reset. The A4988 DIR input has
 *   no pull of its own, so the chip's internal pull-down wins and the board
 *   boots normally. Nothing may drive this line high during reset.
 *
 * GPIO38-42 behave as plain GPIO only because the JTAG-source strap, GPIO3, is
 *   left unconnected. Do not wire anything to GPIO3. */

/* --- I2C: both MPU6050s (and the OLED in the full build) ----------------- */
#define PIN_I2C_SDA             GPIO_NUM_8    /* I2C_SDA */
#define PIN_I2C_SCL             GPIO_NUM_9    /* I2C_SCL */

#define I2C_ADDR_IMU_A          0x68   /**< MPU1: AD0 low  */
#define I2C_ADDR_IMU_B          0x69   /**< MPU2: AD0 high */

/* --- CRSF / ExpressLRS UART ----------------------------------------------
 * Rev 2.0 names these nets from the ESP32's point of view (Rev 1.0 used the
 * receiver's, which is why the old header carried a paragraph about crossing
 * them):
 *
 *   net "TX" -> GPIO17 -> receiver Rx   (ESP32 would transmit here)
 *   net "RX" -> GPIO18 -> receiver Tx   (ESP32 receives CRSF here)
 *
 * The MVP never transmits to the receiver, so the UART is opened RX-only on
 * GPIO18. If no valid CRSF frame arrives there, crsf.c also tries GPIO17 as the
 * receive pin, which rescues a crossed harness. Both pins stay inputs the whole
 * time, so a crossed wire can never put two outputs against each other.
 * ------------------------------------------------------------------------ */
#define PIN_CRSF_ESP_TX         GPIO_NUM_17   /* net "TX" */
#define PIN_CRSF_ESP_RX         GPIO_NUM_18   /* net "RX" */
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

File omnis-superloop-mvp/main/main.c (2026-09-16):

/**
 * @file    main.c
 * @brief   OMNIS superloop MVP — boot sequence and the superloop.
 *
 * ARCHITECTURE (BUILD-LOG.md Planning 1a). One while(1) inside app_main, paced by a 500 Hz
 * GPTimer ISR that does nothing but set a flag. No xTaskCreate, queues,
 * semaphores, mutexes or vTaskDelay anywhere in OMNIS-authored code; ESP-IDF
 * driver internals are treated as part of the hardware. app_main is pinned to
 * CPU1 with CPU1's idle-task watchdog disabled (sdkconfig.defaults), which is
 * what makes a never-yielding loop legal on this chip.
 *
 * BOOT NEVER HALTS ON A PERIPHERAL PROBLEM. A missing IMU, a failed calibration
 * or an RMT failure each become a latched fault (fault.h): the superloop still
 * runs, the buzzer says what is wrong, telemetry prints it, and the supervisor
 * refuses to arm. Only untrustworthy parameters — which everything downstream
 * divides by — or a tick that will not start drop into fault_only_loop().
 *
 * EACH TICK, in this order:
 *   1. sense    IMUs (read, filter, fuse) and radio
 *   2. judge    faults (IMU, link, tilt, overrun), then the supervisor
 *   3. act      flat:    drive pipeline -> acceleration limit -> STEP pulses
 *               balance: lean PID in the balance frame -> STEP pulses
 *               otherwise stop
 *   4. report   buzzer every tick, telemetry once a second
 *
 * Every fault check runs before the motor command on every tick.
 */

#include <inttypes.h>
#include <math.h>
#include <stdio.h>
#include <string.h>

#include "driver/gpio.h"
#include "esp_log.h"
#include "esp_timer.h"

#include "balance.h"
#include "buzzer.h"
#include "crsf.h"
#include "drive.h"
#include "fault.h"
#include "imu.h"
#include "mecanum_kinematics.h"
#include "omnis_config.h"
#include "omnis_params.h"
#include "omnis_pins.h"
#include "rc_input.h"
#include "step_gen.h"
#include "supervisor.h"
#include "tick.h"

static const char *TAG = "omnis";

#define RAD2DEG  57.29578f

static const omnis_params_t *s_params  = NULL;
static fault_state_t          s_faults;
static supervisor_t           s_sup;
static bool                   s_step_ok = false;   /* RMT channels came up          */
static bool                   s_imu_ok  = false;   /* IMUs initialised + calibrated */
static bool                   s_crsf_ok = false;   /* UART installed                */

/* Rates actually handed to the step generator: the drive pipeline's output after
 * the acceleration limit. Kept across ticks because the slew limiter works from
 * where the wheels ARE, not from where they were last asked to be. */
static wheel_rates_t s_cmd_rates = { 0.0f, 0.0f, 0.0f, 0.0f };

/* Balance controller, plus the per-arming summary printed on disarm (telemetry
 * is silent while balancing — see OMNIS_TELEMETRY_IN_BALANCE). */
static balance_cfg_t  s_bal_cfg;
static balance_ctrl_t s_bal;
static float          s_bal_peak_lean = 0.0f;
static uint32_t       s_bal_ticks     = 0u;

/* ==========================================================================
 * Boot helpers
 * ========================================================================== */

/* Board Rev 2.0 has no stepper enable line: the A4988s are live whenever 12 V is
 * present, from before this code runs. The only thing firmware controls is
 * whether STEP pulses exist, so the STEP lines are pinned low before anything
 * else, and stay low until the RMT generator takes them over. */
static void gpio_safe_state(void)
{
    const gpio_config_t steppers = {
        .pin_bit_mask = (1ULL << PIN_FL_STEP) | (1ULL << PIN_FL_DIR)
                      | (1ULL << PIN_FR_STEP) | (1ULL << PIN_FR_DIR)
                      | (1ULL << PIN_RL_STEP) | (1ULL << PIN_RL_DIR)
                      | (1ULL << PIN_RR_STEP) | (1ULL << PIN_RR_DIR),
        .mode         = GPIO_MODE_OUTPUT,
        .pull_up_en   = GPIO_PULLUP_DISABLE,
        .pull_down_en = GPIO_PULLDOWN_DISABLE,
        .intr_type    = GPIO_INTR_DISABLE,
    };
    ESP_ERROR_CHECK(gpio_config(&steppers));
    gpio_set_level(PIN_FL_STEP, 0);  gpio_set_level(PIN_FL_DIR, 0);
    gpio_set_level(PIN_FR_STEP, 0);  gpio_set_level(PIN_FR_DIR, 0);
    gpio_set_level(PIN_RL_STEP, 0);  gpio_set_level(PIN_RL_DIR, 0);
    gpio_set_level(PIN_RR_STEP, 0);  gpio_set_level(PIN_RR_DIR, 0);

    const gpio_config_t buzzer = {
        .pin_bit_mask = (1ULL << PIN_BUZZER),
        .mode         = GPIO_MODE_OUTPUT,
        .pull_up_en   = GPIO_PULLUP_DISABLE,
        .pull_down_en = GPIO_PULLDOWN_DISABLE,
        .intr_type    = GPIO_INTR_DISABLE,
    };
    ESP_ERROR_CHECK(gpio_config(&buzzer));
    gpio_set_level(PIN_BUZZER, BUZZER_OFF);

    ESP_LOGI(TAG, "STEP/DIR held low, buzzer off. NOTE: EN# is hardwired - the "
                  "motors are energised whenever 12 V is present");
}

static void log_params(const omnis_params_t *p)
{
    /* Parallel rollers give the two axles different yaw levers, so print both.
      * A rear lever near zero is EXPECTED on a near-square frame, not a fault. */
    const mecanum_levers_t k = mecanum_yaw_levers(p->geometry.wheelbase_mm,
                                                  p->geometry.track_width_mm);
    ESP_LOGI(TAG, "params v%" PRIu32 ": r=%.1f L=%.1f W=%.1f mm | yaw levers front "
                  "%.1f rear %.1f mm (%.1f:1) | max %.0f st/s, accel %.0f st/s^2, "
                  "deadband %.0f st/s",
             p->schema_version, (double)p->geometry.wheel_radius_mm,
             (double)p->geometry.wheelbase_mm, (double)p->geometry.track_width_mm,
             (double)fabsf(k.fl), (double)fabsf(k.rl),
             (double)(k.rl != 0.0f ? fabsf(k.fl / k.rl) : INFINITY),
             (double)p->step.max_step_rate,
             (double)p->step.max_accel_steps_s2, (double)p->step.deadband_steps);
    const omnis_channel_map_t *m = &p->channel_map;
    ESP_LOGI(TAG, "channels: thr %u pitch %u roll %u yaw %u | arm %u%s mode %u speed %u pot %u",
             m->throttle, m->pitch, m->roll, m->yaw, m->kill_switch,
             m->arm_switch_invert ? " (inverted)" : "", m->drive_mode,
             m->speed_limiter, m->tune_pot);
    ESP_LOGI(TAG, "DIR invert FL %d FR %d RL %d RR %d | pulse %u us",
             p->motor.dir_invert[0], p->motor.dir_invert[1],
             p->motor.dir_invert[2], p->motor.dir_invert[3],
             (unsigned)p->motor.step_pulse_us);
}

/* The verified kinematics cases, re-checked on the Xtensa FPU at boot against
 * the REFERENCE geometry (30 / 223 / 230 mm), not the parameter set — so this
 * checks the code and the FPU, and editing the geometry cannot fake a fault. */
static bool near(float got, float want, float tol)
{
    return fabsf(got - want) <= tol;
}
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

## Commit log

2026-08-16 Add new documentation files for ESP32-S3 WROOM series
    - Added ESP32-S3-WROOM-N16R8 pinout PDF for reference.
    - Included Key Features image to highlight specifications.
    - Added datasheet for ESP32-S3 WROOM-1 and WROOM-1U for detailed technical information.
    [EDGEHAX-S3-PRO-STEP-FILE-3D.step]
2026-08-16 Add new documentation and images for ESP32-S3-WROOM-N16R8
    - Added pinout PDF for ESP32-S3-WROOM-N16R8
    - Included Key Features image for better visualization
    - Added datasheet for ESP32-S3-WROOM-1 and WROOM-1U
    [EDGEHAX-S3-PRO-STEP-FILE-3D.step]
2026-08-16 Update schematic_omnis.pdf with layout adjustments and metadata corrections
2026-08-17 folders rearraged
    [EDGEHAX-S3-PRO-STEP-FILE-3D.step]
2026-08-18 Fix compiler path for ESP32-S3 in c_cpp_properties.json and add esp32-command-reference.md for command lookup
2026-09-05 Add verified mecanum kinematics module and reference docs
    Adds the complete kinematics work for the 4-wheel mecanum drivetrain:
    - mecanum_kinematics.{c,h} — inverse/forward kinematics, common-factor
    clamp, direction-reversal deadband, and the null-space slip metric.
    Fully symbolic in wheel_radius_mm / wheelbase_mm / track_width_mm so
    geometry stays a params.json concern, never baked into the formulas.
    - mecanum-kinematics-reference.md — notation, mixing matrix, sign
    convention table, RC channel mapping, and four verified test cases
    (pure forward, pure strafe, pure rotation, combined) with expected
    step rates for the OMNIS geometry (r=30, L=223, W=230, k=226.5).
    - mecanum-kin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
    [mecanum_kinematics.h]
2026-09-05 Add sensor fusion, attitude EKF and balance PID modules with reference docs
    Companion to assets/kinematics/, covering omnis-info.md §11 (EKF and
    dual-IMU fusion), §12 (calibration hooks) and §13 (balance control).
    Modules — pure arithmetic on caller-owned structs, no allocation, no
    statics, no RTOS primitives, no peripheral access, so all of it is
    host-testable without ESP-IDF or hardware:
    - attitude_ekf.{c,h} — per-IMU 4-state filter [roll, pitch, bias_roll,
    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
2026-09-05 Record as-built chassis geometry and propagate it through all docs
    The board photo and the confirmed front edge (OLED/button end) pin down two
    facts that were previously assumptions, and both change code:
    - The two MPU6050s are mounted ANTIPARALLEL — 0x68 at the front-left corner
    facing forward, 0x69 at the rear-right facing rearward, 180° apart about Z.
    Uncorrected, two healthy sensors read ~20° apart and trip §11c's 15°
    disagreement fault at every boot.
    - Front being a short edge means balance mode tips about body Y, so the lean
    angle is PITCH and roll is gimbal-locked and unused. The grounded pair is
    FL+FR or RL+RR.
    New: assets/control/omnis_imu_mounting.h — the one no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
    [EDGEHAX-S3-PRO-STEP-FILE-3D.step]
2026-09-05 Derive IMU mounting from two poses instead of assuming it; ignore .cache/
    Closes the last open assumption in the estimation stack. The mount constants
    in omnis_imu_mounting.h were read off a silkscreen arrow, and that reading
    was load-bearing in a bad way: a wrong GLOBAL orientation — both IMUs
    consistently rotated — is invisible to every check downstream. The two IMUs
    still agree with each other, so §11c's disagreement fault stays silent while
    the balance controller drives the wrong body axis. Nothing catches it.
    New: imu_mount_resolve(). Recovers the descriptor from two poses with no
    interpretation at all:
    1. chassis flat and level -> pins body +Z (accel reads the up direction,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
    [imu_fusion.h, omnis_imu_mounting.h]
2026-09-05 PLAN.md: record decisions 1b (RMT burst re-arm) and 1c (inner PID only)
    Also records the per-stage requirement to post bench test instructions in
    chat after each stage: what to flash, what to connect, what to do, what a
    pass looks like, and what the common failure looks like.
    Note added under 1b: Option B rules out the Arduino core for step
    generation. Arduino's RMT wrapper has no transaction queue — its own header
    states a second rmtWriteAsync() issued mid-transfer returns false — so only
    rmtWriteLooping() (Option A) is reachable there.
2026-09-05 PLAN.md approved: record decision 1a (ESP-IDF, not Arduino)
    Checkpoint of the fully-settled plan before any implementation code exists.
    Arduino IDE was offered as a way to satisfy the no-FreeRTOS goal and was
    rejected on evidence rather than preference:
    - It does not remove FreeRTOS. loop() IS a FreeRTOS task — the installed
    core's own cores/esp32/main.cpp:113 calls xTaskCreateUniversal(loopTask,
    ...). Arduino moves the xTaskCreate out of your code and into the core
    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
2026-09-05 Stage 1: project skeleton, pin map, params, and the 500 Hz tick
    First code of the superloop MVP. Timing spine only — no motors, no IMUs, no
    radio. Builds clean with zero warnings; 154 KB binary, 85% of the app
    partition free.
    - CMakeLists.txt / main/CMakeLists.txt — standalone IDF project alongside the
    root one, MINIMAL_BUILD ON. Build with idf.py -C omnis-superloop-mvp build.
    - sdkconfig.defaults — the settings that make a superloop legal on this chip:
    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
2026-09-07 Stage 1 verified on hardware; fix biased rate reporting
    Bench test passed on the EdgeHax S3 Pro. Over 10 one-second windows:
    overruns 0, period 2000-2000 us with no measurable jitter, geometry printing
    k=226.5 / k/r=7.550 exactly, and COM_ENA driven disabled before anything else
    could move. Headroom is 1998 us of 2000 — the Stage 1 loop body costs ~2 us,
    leaving 99.9% of the budget for later stages.
    Two things could only be confirmed on hardware and were:
    - "main_task: Started on CPU1" — the affinity pinning took effect, which is
    the premise the plain-volatile tick flag rests on.
    - No task-watchdog trip across 10 s of a never-yielding loop — the CPU1
    idle-watchdog setting took eff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
    [main.c]
2026-09-07 Stage 2: kinematics port, RC mapping, and the drive pipeline
    Ports the verified mecanum kinematics in unchanged and builds the drive-command
    path on top of it. 76 host assertions pass, 0 fail. Firmware builds clean with
    zero warnings; 161 KB, 85% of the partition free.
    - main/mecanum_kinematics.{c,h} — byte-identical copy of assets/kinematics/,
    confirmed by diff as part of the stage's verification. The value of that
    module is that its numbers are checked, so retyping it would throw that away.
    - main/drive.{c,h} — RC sticks to body velocity, plus drive_solve() running the
    whole pipeline in the order reference §6 requires.
    - test/test_kinematics.c + run_host_tests.sh — Cases A-D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
    [main.c, mecanum_kinematics.h, omnis_params.c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]
2026-09-15 Migrate to board Rev 2.0 pinout; record change of process
    The builder supplied the Rev 2.0 schematic and asked for every remaining stage
    to be completed in one pass with each step committed, since Claude access lapses
    for ~2 months and the board is not yet assembled. Per-stage approval is replaced
    by per-stage commits, zero-warning target builds, host tests, and a TESTING.md
    for the bench. Recorded in PLAN.md.
    Pinout verification: three sources existed — the attached image,
    assets/pcb/OMNIS.kicad_sch, and the planning doc rev2-pin-assignment.md. Every
    ESP32 pin was traced through the KiCad wire segments to its global label rather
    than read off a picture. The image and schematic agree on a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
    [main.c, omnis_pins.h]
2026-09-15 Fix pid_t POSIX collision and balance-mode pitch fold in control assets
    Two latent bugs in assets/control/, found by reading ahead before porting the
    modules into the firmware. Fixed at the source so the asset folder and the
    firmware copies stay byte-identical.
    1. pid_t collides with POSIX. pid.h declared typedef struct {...} pid_t, but
    pid_t is the process-id type in sys/types.h, which ESP-IDF headers include
    throughout. Reproduced on both xtensa-esp32s3-elf-gcc ("conflicting types for
    'pid_t'") and host clang once sys/types.h is in scope; the host test had only
    passed because nothing it included reached that header. Renamed to
    pid_ctrl_t. pid.c, attitude_ekf.c and imu_fusio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
    [omnis_imu_mounting.h]
2026-09-15 Stage 3: MPU6050 driver, IMU orchestration, EKF and fusion ported
    Brings both IMUs up on the shared I2C bus, calibrates gyro bias at boot, and
    runs both attitude filters plus dual-IMU fusion every tick.
    - mpu6050_regs.h: register map, configuration values and a pure 14-byte burst
    decoder, host-tested (28 assertions: decoding, sign extension, full scale,
    plausibility, identity).
    - mpu6050.{c,h}: I2C transport on the ESP-IDF v6 i2c_master API.
    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
2026-09-15 Stage 4: CRSF parser, RC input decoding, and RX-only UART glue
    Receives ExpressLRS CRSF on UART1 and turns it into sticks, an arm request,
    drive mode, speed limit and a tuning pot value. The drive pipeline now runs on
    real sticks instead of the Stage 2 synthetic circle; nothing drives a motor yet.
    - crsf_parser.{c,h}: pure parser — framing, CRC-8/DVB-S2, 16 x 11-bit channel
    unpacking, link statistics.
    - rc_input.{c,h}: pure decode of channels using the params channel map.
    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
2026-09-15 Stage 5: RMT STEP generation, acceleration limit, and bench pattern
    Generates STEP/DIR for all four A4988s on the ESP32-S3's four RMT TX channels
    using the burst re-arm strategy chosen in PLAN.md §1b. In a normal build the
    motors still never step; the supervisor that arms them arrives next.
    - step_wave.{c,h}: pure waveform generator — rate in, RMT-style symbols out,
    phase carried across chunks.
    - step_gen.{c,h}: RMT glue — per-wheel burst queueing, exact queue regulation,
    DIR reversal state machine, and a race-free stop.
    - drive_slew_rates(): acceleration limit by a common factor.
    - motor params (per-wheel DIR invert, 10 us pulses, 10 us minimum low),
    RMT callback and encoder in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
    [main.c, omnis_config.h, omnis_params.c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]
2026-09-15 Stage 6: fault latch, buzzer patterns, arming supervisor, integration
    Adds the layer that decides whether the motors may move. On board Rev 2.0,
    where the A4988 enable is hardwired, this is the entire safety story: STEP
    pulses exist only in ARMED_FLAT or ARMED_BALANCE, and every other state stops
    the step generator every tick.
    - fault.{c,h}: pure latch with three clearing classes — FOREVER (parameters, IMU
    init/calibration/comm/disagreement, step-generator init), UNTIL-DISARM (tilt,
    overrun), LIVE (radio link). Any active fault blocks arming and disarms.
    - buzzer_pattern.{c,h} + buzzer.{c,h}: distinct on/off patterns (tested pairwise
    distinguishable) and an event-over-fault player.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
    [buzzer.c, fault.h, main.c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]
2026-09-16 Stage 7: balance controller and full integration
    Completes the MVP: the robot can arm in flat mode and drive, or be tipped onto a
    wheel pair and balance, with the lean PID running in the balance frame.
    - balance.{c,h}: lean PID (derivative from the raw gyro) integrated into a
    forward speed, mapped to the grounded pair, with the outer velocity-bias loop
    wired but off per PLAN.md decision 1c.
    - main.c: switches the estimation frame and re-seeds the filters when balance is
    armed, holds still through the settle state, runs the balance path, raises a
    tilt fault from balance-frame lean, and prints a summary on disarm.
    - balance params (accel clamp, stick mapping, tilt limit, invert, tunin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
    [main.c, omnis_config.h, omnis_params.c]
2026-09-16 Docs: bench bring-up guide, README, annotated info file, plan marked complete
    Completes the process steps PLAN.md asked for, now that all seven stages are
    built and committed.
    - TESTING.md: the bench bring-up procedure, stage by stage — setup, what to do,
    what a pass looks like, and what each failure means. Opens with the Rev 2.0
    safety situation (EN# hardwired: motors energise with 12 V, before firmware
    runs, and only unplugging de-energises them), and covers the four things most
    likely to need changing on first contact with hardware: IMU mount constants,
    motor DIR flags, radio channel order and stick polarity, and balance gains.
    Includes the balance sign check, which disting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
2026-09-16 Kinematics: re-derive IK/FK for the lateral parallel roller layout
    The wheels are no longer in an X-drive. Mounting-shaft and motor constraints
    put the SAME roller tilt on both left wheels (FL, RL) and the mirrored tilt on
    both right wheels (FR, RR), so the standard mixing matrix no longer describes
    the hardware.
    Re-derived from first principles rather than sign-flipped. Per wheel:
    r*omega_i = vx + delta_i*vy + w*(delta_i*x_i - y_i)
    which for this layout gives different yaw lever arms on the two axles —
    front +/-(L+W)/2, rear +/-(L-W)/2 — where the X-drive had (L+W)/2 on all four.
    What changed:
    - Handedness is now four named constants (MECANUM_DELTA_*), the only place
    the l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
    [main.c, mecanum_kinematics.h, omnis_config.h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]
2026-09-16 Docs: re-derive the kinematics asset docs for the parallel roller layout
    All three kinematics documents rewritten against the as-built layout rather
    than patched. The previous edition described a textbook X-drive that the
    hardware no longer is.
    derivation.md — second edition, re-derived from (4.1) onward:
    - §1, §3 state the layout and draw the roller tilts on the frame diagram.
    - §2 fixes the glyph convention explicitly (the drawn line is the roller
    AXIS, seen from above, robot facing up the page, +y to the page-left).
    Two mirror-image conventions exist; picking one consistently is not the
    same as being right about the hardware, so §5.3 carries the bench test
    that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
    [omnis_imu_mounting.h]
2026-09-16 Docs: add OPERATIONS_GUIDE, rewrite root README, sync every doc to the layout
    OPERATIONS_GUIDE.md (new, omnis-superloop-mvp/):
    - Build and flash, including why the IDF activation script is used rather
    than export.sh (it looks for a py3.11 venv against a py3.14 install).
    - The superloop explained: the 500 Hz tick and what the ISR does and does
    not do, the SENSE/JUDGE/ACT/REPORT ordering and why it is that order, how
    STEP pulses reach the pins without a task, and the Rev 2.0 failsafe.
    - File-by-file index of all 44 sources, grouped by responsibility.
    - Tuning cheat sheet: dir_invert, roller handedness, chassis dimensions,
    speed and yaw scaling, stepper limits, STEP timi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
    [omnis_params.c]
2026-09-16 Docs: correct the last stale roller-pair claim, in sensor-fusion-reference
    The fusion reference repeated the same claim already fixed in
    omnis_imu_mounting.h: that FL/RR, the diagonal the two IMUs sit on, is also a
    roller-handedness pair. That was true of the X-drive layout and is not true of
    the as-built parallel one, where the delta = -1 pair is the left SIDE, FL and
    RL. Nothing in the fusion code ever depended on it.
    Found by a full sweep of all 22 markdown files for stale kinematics formulas
    and RTOS assumptions. Everything else came back clean: no old IK row and no
    old FK yaw scale survives anywhere, and the remaining FreeRTOS references are
    either the no-RTOS rule itself or sections o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
2026-09-16 Docs: regenerate BUILD-LOG's commit hashes after the history rewrite
    The Co-Authored-By trailers were stripped from all 22 commit messages that
    carried them, which changed every hash from 17175e6 onward. BUILD-LOG's
    stage-by-stage table cited 14 of those by hash and would otherwise have
    pointed at commits that no longer exist.
    Verified before rewriting: the tree hash of the rewritten branch is identical
    to the original (b9bb949), all 41 commit subjects are unchanged, and every
    commit is authored by dodiyakh@gmail.com. The pre-rewrite history is kept on
    the local branch backup/pre-trailer-strip.
2026-09-22 Docs: update RC channel mapping for throttle, roll, and additional controls
2026-09-23 Docs: update GPIO pin assignments and remove MPU6050 interrupt documentation
2026-09-26 Fix front-right stepper GPIO assignment
    [omnis_pins.h]
2026-09-26 Document corrected front-right pin mapping
    [omnis_pins.h]
2026-09-26 Sync pin comments with revised PCB routing
2026-09-26 Add CMake configuration files for IMU diagnostic and main components
2026-09-26 fix(imu): support MPU6515/MPU6500 and reliable burst reads
    Add device-specific WHO_AM_I handling and parsing, validate raw bursts, improve I2C diagnostics, and increase per-read timeout to match the known-good diagnostic.
    [imu.c, mpu6050.c]
2026-10-02 Revise verification statuses in README table
    Updated verification status for stages 2 to 6 in README.
